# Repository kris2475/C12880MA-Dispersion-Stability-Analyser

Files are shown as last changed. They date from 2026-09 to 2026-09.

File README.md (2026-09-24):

# Multiwavelength Dispersion Analyser

A low-cost, highly portable optical sensing platform designed for field and lab use, pairing the **Hamamatsu C12880MA micro-spectrometer** with its **onboard PCB LED illumination source** to track stability, flocculation, agglomeration, and sedimentation dynamics in complex liquid dispersions.

Traditional stability analysers rely on single-wavelength light sources and a single photodiode, capturing only a blunt aggregate transmission number. This project evolves that proven industrial concept into a full-spectrum (340 - 850 nm) optical tool. By monitoring every wavelength simultaneously, the system can decouple overall scattering mass from time-dependent particle size shifts, micro-bubble relaxation phases, and differential sedimentation.

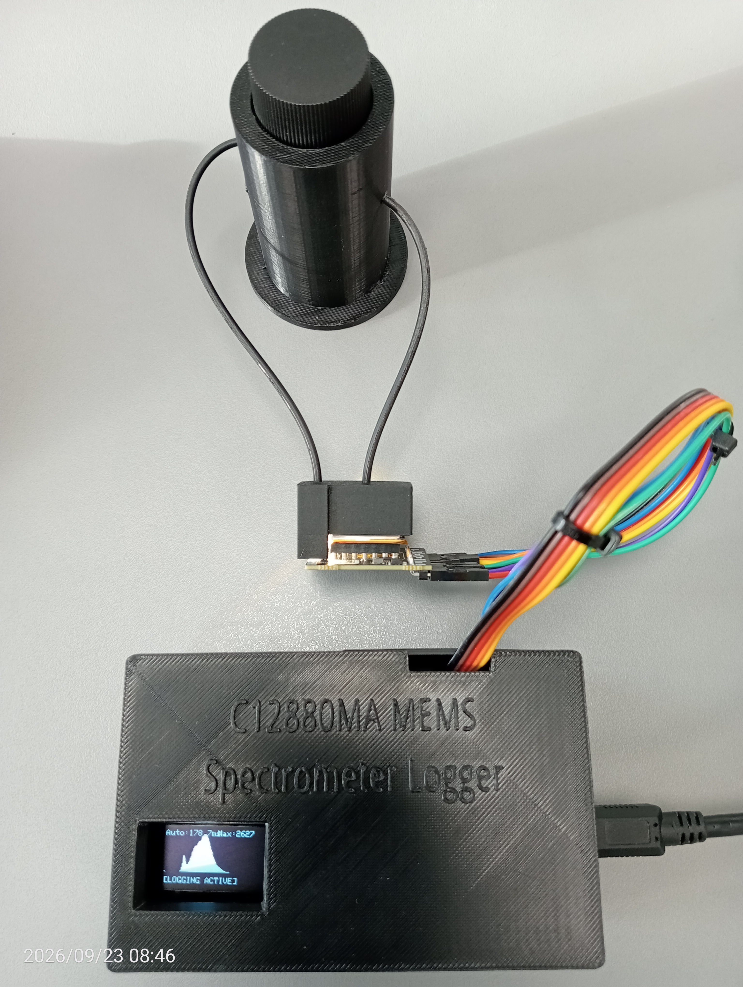
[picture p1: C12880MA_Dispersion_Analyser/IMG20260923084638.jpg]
Multiwavelength Dispersion Analyser


---

## System Architecture & Field Portability

Engineered for rapid deployment outside the traditional laboratory, the device combines low-power microcontrollers with precision optical hardware:

* **0° Transmission & Extinction Axis:** The primary operational path, tracking total optical density, scattering, and initial de-aeration/bubble-clearing behaviour immediately after sample agitation.
* **Multi-Angle Optical Probing:** Configurable housing geometry designed to capture multiwavelength extinction and scattering profiles across the entire visible-to-near-infrared spectrum.

---

## Sensor Layout & Dark Pixel Reference

The Hamamatsu C12880MA sensor array comprises 288 total channels. The 288-pixel spectral detector provides a full 340–850 nm spectral measurement at approximately 12 nm FWHM resolution. The first 87 columns (**P0 through P86**) correspond to a dedicated sequence of physically shielded pixels on the sensor die. 

Rather than relying on an isolated external reference, these masked elements capture the sensor's native dark current, reset noise, and electronic baseline offsets in real time. The firmware uses this continuous block for thermal drift and offset subtraction on every individual scan, ensuring high repeatability in field conditions.

---

## Hardware Bill of Materials

* **Micro-Spectrometer & Light Source:** Hamamatsu C12880MA micro-spectrometer module utilising its **onboard PCB LED** as the illumination source (288-pixel CMOS image sensor with a reflection grating, 340 - 850 nm range; features 87 optically shielded dark pixels, P0 - P86, for real-time baseline noise subtraction).
* **Microcontroller:** ESP32 Dev Module (handling precise clock timing, ADC attenuation, OLED interface, and SD card logging).
* **Housing:** Custom 3D-printed matte black, lightweight portable enclosure optimised for standard optical vials/cuvettes and secure alignment with the spectrometer PCB.

---

## Dispersion Physics & Kinetic Analysis Pipeline

By capturing full-spectrum temporal data (e.g., minute-by-minute logs of shaken suspensions like turmeric or starch in water), the companion Python and firmware tools extract rich kinetic metrics underpinned by fundamental optical scattering and fluid dynamics principles:

1. **Sedimentation Tracking (Total Scattering Mass & Stokes' Law):** 
   * Monitors the total integrated intensity across all active wavelengths to evaluate overall suspended particle mass in real time.
   * Captures initial preparation artefacts, such as micro-bubble clearance and de-aeration phases immediately following sample agitation.
   * Reflects bulk particle concentration changes governed by gravitational settling dynamics (approximate Stokes' settling), where particle size, mass density differentials, and fluid viscosity dictate how matter migrates relative to the optical path.

2. **Agglomeration & Flocculation Tracking (Mie vs. Rayleigh Scattering & Spectral Slope Ratios):** 
   * Computes multiwavelength intensity ratios (e.g., $650\text{nm} / 450\text{nm}$) to detect continuous changes in spectral tilt and slope as particles interact and evolve.
   * **Rayleigh Regime ($d \ll \lambda$):** Applies when scattering particles are significantly smaller than the incident wavelength (typically $d < \lambda / 10$). Here, scattering efficiency scales steeply with the inverse fourth power of wavelength ($\lambda^{-4}$), causing much stronger scattering at shorter wavelengths (blue/UV) than longer wavelengths (red/NIR).
   * **Mie Regime ($d \approx \lambda$):** Applies when particle diameters are comparable to the wavelength of light, which is characteristic of practical suspensions, emulsions, and colloidal dispersions (such as starch or turmeric granules). In this regime, the wavelength dependence becomes much weaker and non-monotonic, scaling inversely with $\lambda$ to a lower power or exhibiting complex resonance patterns.
   * **Tracking Agglomeration:** By measuring how the full spectrum shifts across these optical regimes, the system isolates differential sedimentation and flocculation, revealing how heavier or coarser aggregates drop out rapidly while finer fractions remain suspended or form loose structural clusters that alter the wavelength-dependent scattering profile.

3. **Peak Wavelength & Structural Shape Shifts:** 
   * Identifies discrete shifts, broadening, or fluctuations in maximum scattering peaks over extended time series.
   * Decouples bulk chemical identity and baseline intensity changes from physical structural modifications, confirming whether the primary scattering centre remains stable while localised clustering, swelling, or spatial redistribution occurs within the dispersion.

---

## Firmware & Field-Ready Data Logging

The companion ESP32 firmware features an interactive serial interface supporting deployment in the field:
* **Real-Time Auto-Exposure:** Automatically scales integration time (11 ms to 1 s) to keep peak ADC values within optimal target bounds.
* **Periodic Interval Datalogging (`LOG <sec>`):** Automatically saves timestamped spectral frames to an attached SD card at user-defined intervals (ideal for tracking long-term stability curves over 30 to 60+ minutes).
* **Burst Capture (`B`):** Rapidly captures a RAM buffer following a pre-flight auto-exposure stabilisation phase.
* **Metadata Tagging (`COMMENT <text>`):** Appends custom text tags directly to log entries for field sample tracking.

## Experimental Results

To validate the multiwavelength pipeline under real-world conditions, a dynamic stability test was performed using a turmeric-in-water dispersion over a 36-minute time series. Following manual agitation, the sample was logged continuously to capture both transient mixing artifacts and long-term suspension relaxation.

### 1. Raw Spectral Evolution: Waterfall & Spectrogram View
The initial optical behavior of the dispersion is captured across the raw spectral response. 

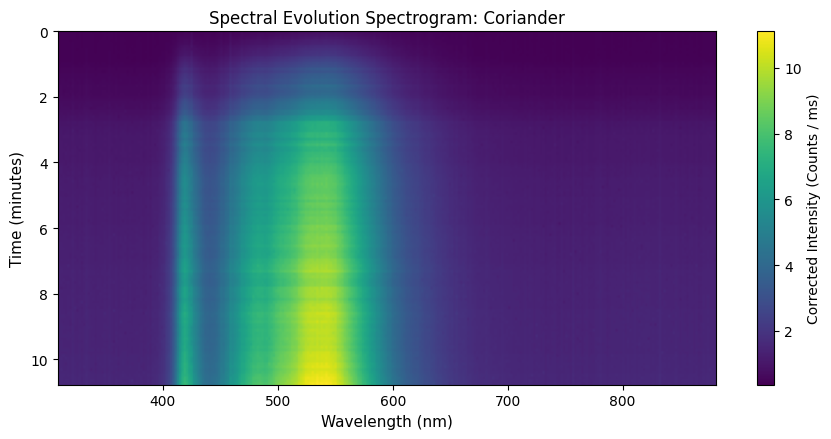
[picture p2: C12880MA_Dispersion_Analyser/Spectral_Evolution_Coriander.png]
Waterfall plot of coriander dispersion spectra
 
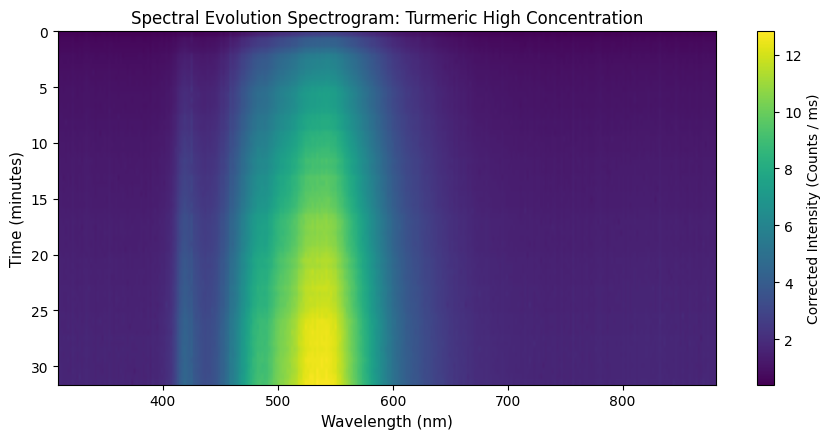
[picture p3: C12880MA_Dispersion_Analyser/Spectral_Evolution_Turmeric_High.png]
Waterfall plot of turmeric_high dispersion spectra
 
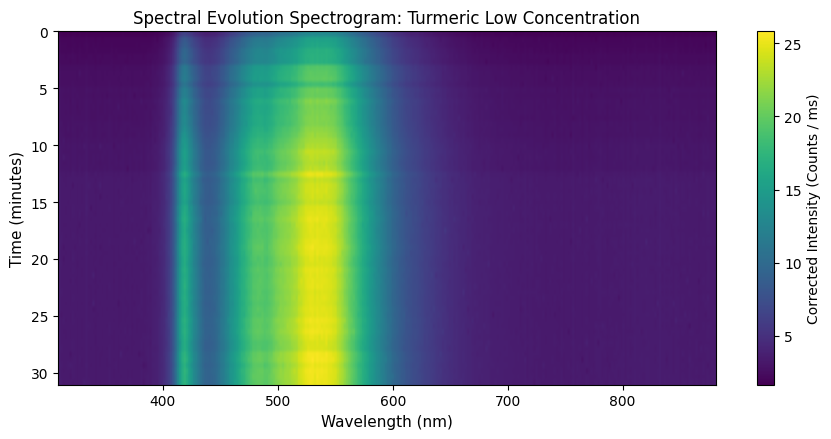
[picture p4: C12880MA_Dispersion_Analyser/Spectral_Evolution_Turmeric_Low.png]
Waterfall plot of tumeric_low dispersion spectra
 
---

* **What we are seeing:** The raw waterfall/overlay plot above demonstrates the complete spectral signature captured by the Hamamatsu C12880MA spectrometer, ranging from the UV-visible cutoff through the characteristic curcuminoid absorption and scattering bands (peaking around 560 – 590 nm). 
* **Connection to the Pipeline:** This corresponds directly to the raw data input stage of our pipeline. Unlike a single-wavelength sensor that only logs a single scalar value, this full spectral sweep captures the entire optical envelope at every 60-second time step. The dense vertical lines visible in early iterations highlight how the hardware pixel resolution responds across the spectrum before baseline dark-correction is applied.

---

### 2. Kinetic Breakdown & Multi-Parameter Analysis

To understand the physical phenomena occurring inside the vial across the multiple spice suspension trials (**Turmeric High**, **Turmeric Low**, and **Coriander**), the raw spectra were processed through the multiwavelength analytical framework. This yielded three distinct diagnostic time profiles revealing how each sample's optical properties change over time due to processes like micro-bubble dissipation, particle rearrangement, and structural settling.

* **Important Context:** Each dispersion was vigorously shaken before logging, which significantly influences initial spectral readings due to temporary air-bubble generation and artificially depressed optical transmission. Following the initial clearance phase, distinct sedimentation and particle dynamics unfold depending on the substance and concentration.

---

### Panel 1: Sedimentation Tracking (Total Scattering Mass)
* **What it shows:** Normalised total integrated intensity starts at a baseline of 100% and climbs progressively across all trials, though with drastically different magnitudes:
  * **Turmeric Low Concentration** rises to approximately 200%.
  * **Turmeric High Concentration** increases to over 400%.
  * **Coriander** climbs steeply up to nearly 800%.
* **Physics Connection:** This unmasks the initial micro-bubble clearance phase. Manual shaking introduces micro-bubbles that severely scatter and block light, depressing early signal counts. As these bubbles rapidly migrate to the surface and dissipate, the optical path clears, revealing the true underlying backscattering behavior and localised particle accumulation within the probe's sensing zone.

### Panel 2: Agglomeration / Flocculation Tracking (Spectral Slope)
* **What it shows:** The intensity ratio between 650 nm and 450 nm demonstrates a consistent downward trajectory across all datasets from different initial points:
  * **Coriander** drops from ~1.25 down to a stable baseline around ~0.78.
  * **Turmeric High** drops from ~2.75 down to ~1.5.
  * **Turmeric Low** drops from ~1.06 down to ~0.75.
* **Physics Connection:** The steep early drop is heavily driven by the transient clearance of micro-bubbles. Once the optical path clears, the true physical dynamics emerge—reflecting structural relaxation, particle rearrangement, and changes in multi-wavelength scattering efficiencies before flattening into stable operational baselines.

### Panel 3: Peak Shift Tracking
* **What it shows:** The apex wavelength of the primary dispersion band oscillates within a stable spectral band (e.g., fluctuating between ~590 nm and ~602 nm for Coriander), featuring sharp quantisation steps and occasional transient spikes.
* **Physics Connection:** This demonstrates the operational limits of pixel-resolution quantisation on discrete spectrometer arrays. As the true optical peak center shifts subtly, the algorithm snaps between adjacent physical pixel columns, while transient spikes capture momentary bulk shifts where local particle migrations alter the spectral envelope's centre of mass.

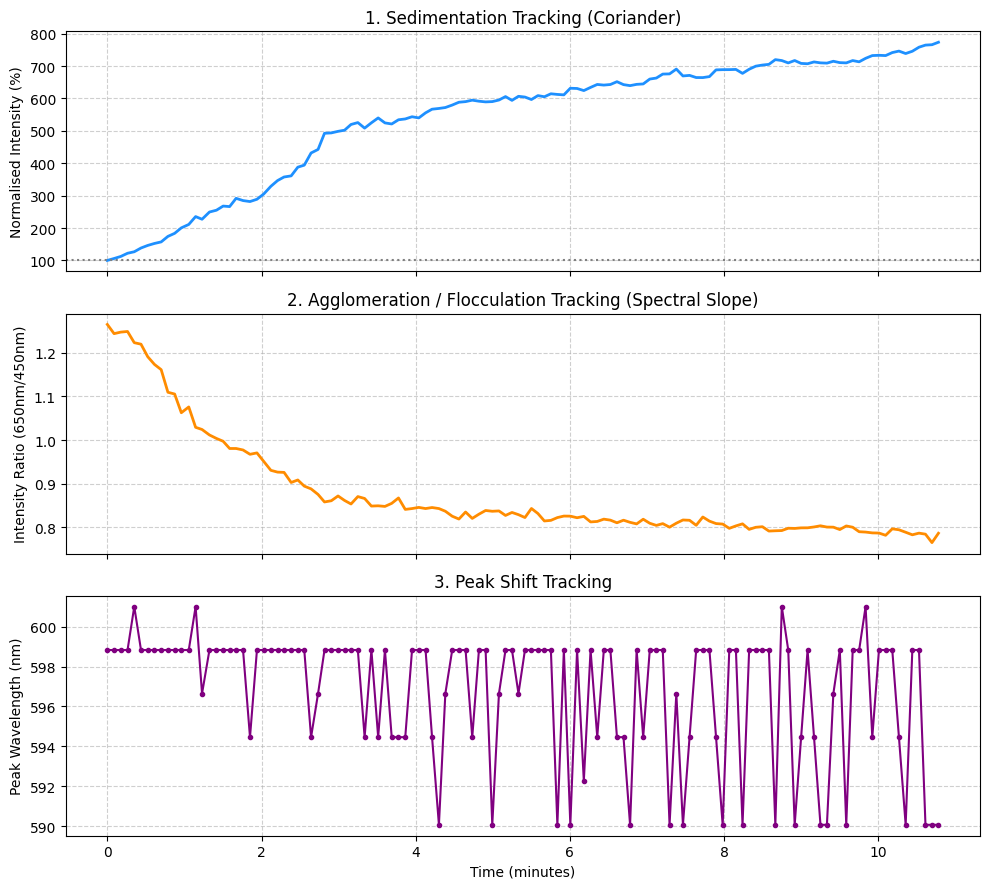
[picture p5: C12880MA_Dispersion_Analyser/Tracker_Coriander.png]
Three-panel kinetic analysis of coriander dispersion

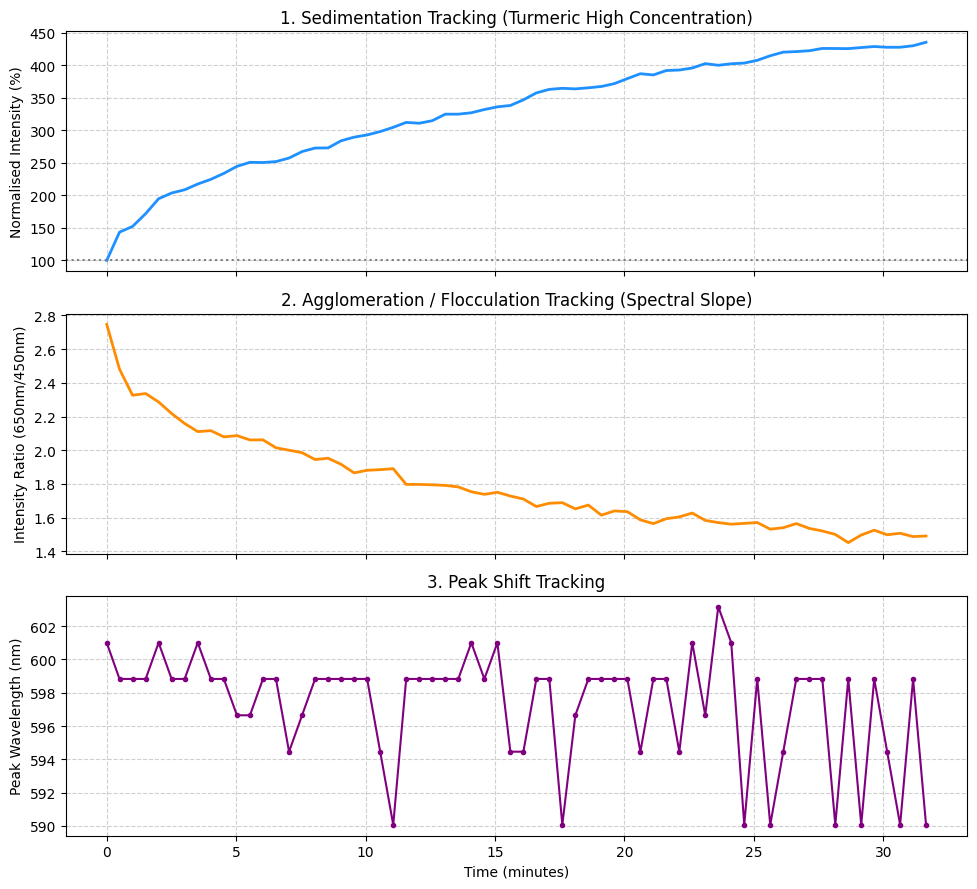
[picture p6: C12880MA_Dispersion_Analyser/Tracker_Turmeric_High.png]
Three-panel kinetic analysis of turmeric_high dispersion

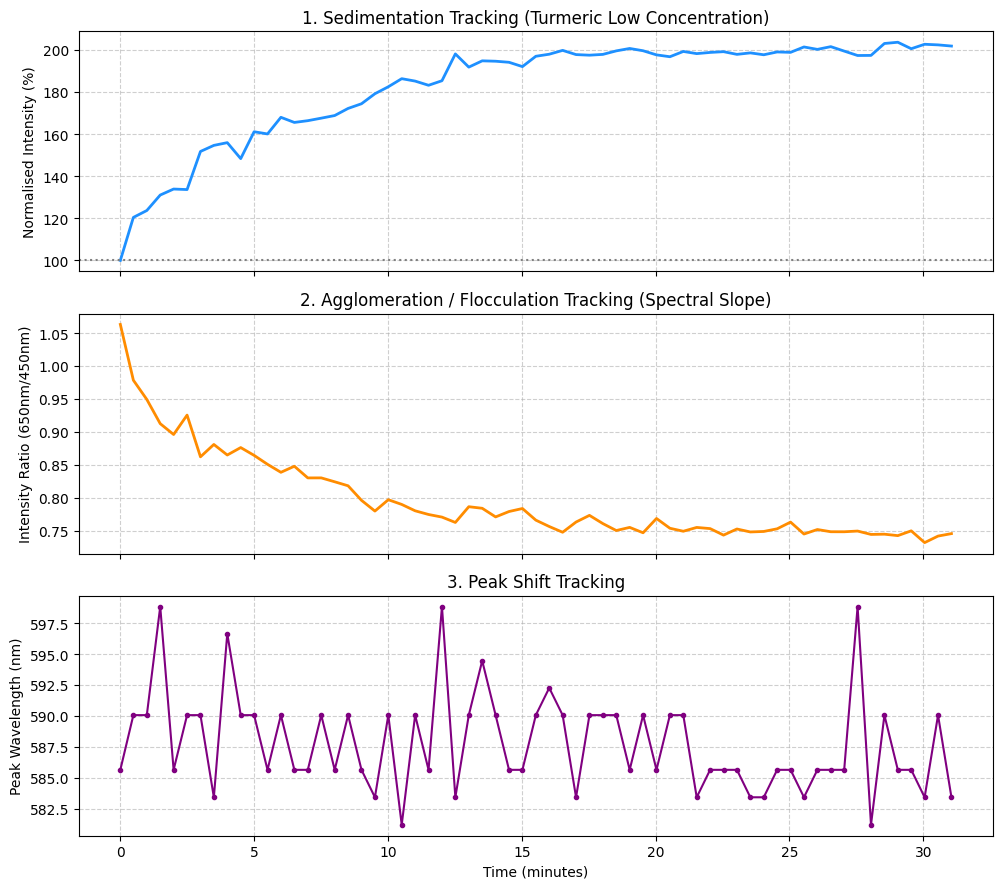
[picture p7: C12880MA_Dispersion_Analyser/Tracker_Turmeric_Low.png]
Three-panel kinetic analysis of turmeric_low dispersion


### 3. Sedimentation vs. Spectral Ratio

### Correlation and Regression Dynamics

The strong negative Pearson correlation coefficients observed across all spice dispersion trials—**Turmeric Low Concentration** ($r = -0.9834$), **Turmeric High Concentration** ($r = -0.9880$), and **Coriander** ($r = -0.9419$)—are clearly illustrated in the comparative scatter plot below. 

These visualisations confirm a robust inverse relationship mapping optical scattering mass (sedimentation proxy) against spectral slope dynamics, which are heavily influenced during the early phase by micro-bubble clearance and subsequent particle rearrangement.

* **Turmeric High Concentration:** $y = -0.003x + 2.867$ ($R^2 = 0.98$)
* **Turmeric Low Concentration:** $y = -0.003x + 1.283$ ($R^2 = 0.97$)
* **Coriander:** $y = -0.001x + 1.196$ ($R^2 = 0.89$)

### Optical Confounding: Physical Scattering vs. Chemical Absorption

While the $650\,\text{nm} / 450\,\text{nm}$ ratio provides a clean empirical proxy for tracking sedimentation dynamics, it is inherently subject to optical confounding. In suspensions containing complex organic matter like turmeric, physical particle scattering and chemical absorption occur simultaneously and blend together into a single measurement:

* **The Chemical Component:** Turmeric contains curcumin, a potent pigment that heavily absorbs blue light around $430\text{--}450\,\text{nm}$. This strong chemical absorption artificially elevates the starting ratio compared to neutral spices or mineral silts.
* **The Physical Component:** As larger aggregates and particles settle out, the overall cloudiness drops, altering the Mie-scattering slope across the spectrum. 

Rather than acting as a pure, isolated measure of physical turbidity, the $650\,\text{nm} / 450\,\text{nm}$ ratio captures a coupled fingerprint of both particle-size evolution and chemical concentration. While this complicates single-variable physical modeling, it creates a highly repeatable, distinct composite signature that downstream machine learning pipelines can leverage to simultaneously resolve physical settling behavior and chemical composition.

### 3. Sedimentation vs. Spectral Ratio

### Correlation and Regression Dynamics

The strong negative Pearson correlation coefficients observed across all spice dispersion trials—**Turmeric Low Concentration** ($r = -0.9834$), **Turmeric High Concentration** ($r = -0.9880$), and **Coriander** ($r = -0.9419$)—are clearly illustrated in the comparative scatter plot below. 

These visualisations confirm a robust inverse relationship mapping optical scattering mass (sedimentation proxy) against spectral slope dynamics, which are heavily influenced during the early phase by micro-bubble clearance and subsequent particle rearrangement.

* **Turmeric High Concentration:** $y = -0.003x + 2.867$ ($R^2 = 0.98$)
* **Turmeric Low Concentration:** $y = -0.003x + 1.283$ ($R^2 = 0.97$)
* **Coriander:** $y = -0.001x + 1.196$ ($R^2 = 0.89$)

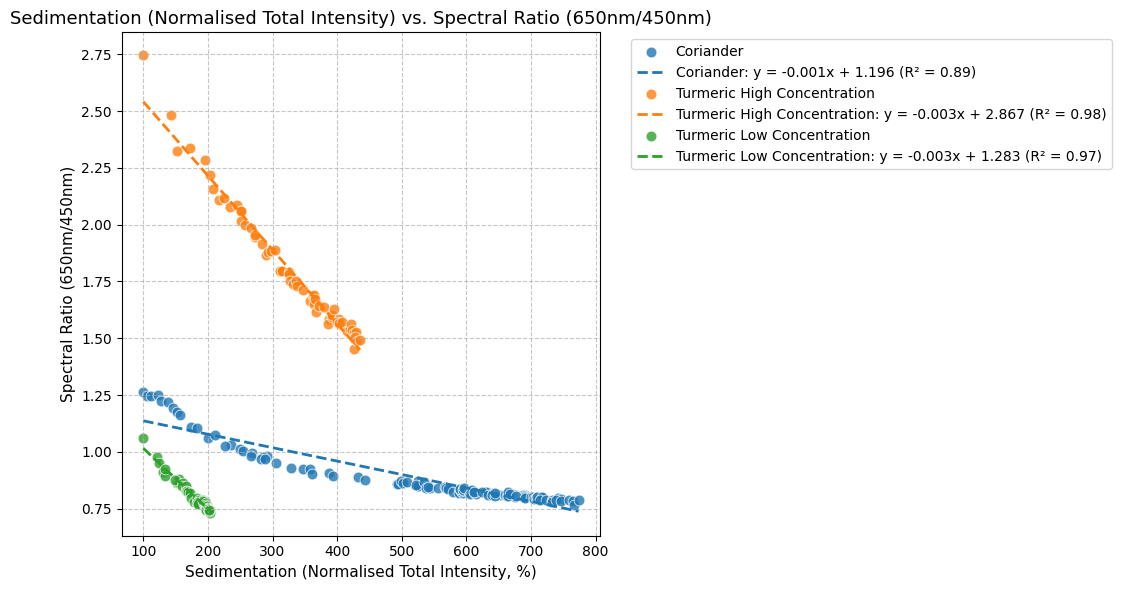
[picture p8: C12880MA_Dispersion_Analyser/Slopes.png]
Sedimentation vs. Spectral Ratio


#### Correlation Analysis & Physical Coupling
* **Axes & Range:** The plot maps the Normalised Total Intensity (%) from a baseline of 100 % up to approximately 780 % on the x-axis - varying by substance up to ~205 % for Turmeric Low, ~440 % for Turmeric High, and ~780 % for Coriander - against the 650 nm/450 nm Spectral Ratio spanning from ~0.74 up to ~2.75 on the y-axis.
* **Inverse Proportionality:** As the Normalised Total Intensity increases across all trials (driven heavily in the initial phase by the rapid clearance of scattering micro-bubbles and enhanced optical path clarity), the Spectral Ratio systematically decreases for each respective dataset, following strong linear regression fits:
  * **Coriander:** $y = -0.001x + 1.196$ ($R^2 = 0.89$)
  * **Turmeric High Concentration:** $y = -0.003x + 2.867$ ($R^2 = 0.98$)
  * **Turmeric Low Concentration:** $y = -0.003x + 1.283$ ($R^2 = 0.97$)
* **Physical Significance:** This tight coupling demonstrates that the optical evolution of the dispersions is governed by simultaneous mechanisms: the progressive elimination of transient micro-bubble and scattering obstructions aligns directly with the structural relaxation and settling of larger particle agglomerates into a stable colloidal state.

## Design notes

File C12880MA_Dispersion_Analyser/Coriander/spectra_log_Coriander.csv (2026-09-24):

Timestamp | IntegrationTime_us | LED_State | Comment | Max_ADC | P0 | P1 | P2 | P3 | P4 | P5 | P6 | P7 | P8 | P9 | P10 | P11 | P12 | P13 | P14 | P15 | P16 | P17 | P18 | P19 | P20 | P21 | P22 | P23 | P24 | P25 | P26 | P27 | P28 | P29 | P30 | P31 | P32 | P33 | P34 | P35 | P36 | P37 | P38 | P39 | P40 | P41 | P42 | P43 | P44 | P45 | P46 | P47 | P48 | P49 | P50 | P51 | P52 | P53 | P54
2026-09-23 20:37:54.456 | 1000000 | ON | coriander | 861 | 371 | 428 | 417 | 416 | 421 | 414 | 448 | 416 | 406 | 420 | 403 | 429 | 436 | 425 | 419 | 407 | 400 | 410 | 400 | 413 | 416 | 405 | 432 | 409 | 400 | 409 | 369 | 411 | 405 | 404 | 394 | 402 | 393 | 393 | 403 | 405 | 402 | 397 | 389 | 414 | 391 | 419 | 406 | 400 | 416 | 425 | 405 | 432 | 411 | 418 | 448 | 442 | 476 | 490 | 483
2026-09-23 20:37:59.706 | 1000000 | ON | coriander | 997 | 368 | 446 | 422 | 412 | 420 | 413 | 444 | 410 | 402 | 418 | 400 | 418 | 439 | 431 | 416 | 410 | 398 | 406 | 406 | 401 | 415 | 411 | 435 | 412 | 400 | 411 | 395 | 403 | 401 | 406 | 400 | 401 | 391 | 418 | 410 | 402 | 400 | 387 | 398 | 414 | 391 | 419 | 404 | 399 | 413 | 429 | 411 | 435 | 416 | 430 | 458 | 454 | 496 | 528 | 533
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

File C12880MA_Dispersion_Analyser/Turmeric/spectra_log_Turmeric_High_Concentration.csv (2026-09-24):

Timestamp | IntegrationTime_us | LED_State | Comment | Max_ADC | P0 | P1 | P2 | P3 | P4 | P5 | P6 | P7 | P8 | P9 | P10 | P11 | P12 | P13 | P14 | P15 | P16 | P17 | P18 | P19 | P20 | P21 | P22 | P23 | P24 | P25 | P26 | P27 | P28 | P29 | P30 | P31 | P32 | P33 | P34 | P35 | P36 | P37 | P38 | P39 | P40 | P41 | P42 | P43 | P44 | P45 | P46 | P47 | P48 | P49 | P50 | P51 | P52 | P53 | P54
2026-09-24 07:35:05.778 | 932296 | ON | Turmeric_Strong | 2675 | 368 | 464 | 464 | 463 | 463 | 461 | 502 | 459 | 455 | 462 | 448 | 478 | 506 | 483 | 464 | 453 | 441 | 449 | 452 | 461 | 468 | 457 | 495 | 451 | 441 | 460 | 434 | 455 | 451 | 458 | 436 | 443 | 441 | 437 | 451 | 451 | 448 | 432 | 437 | 458 | 432 | 475 | 461 | 442 | 466 | 481 | 455 | 491 | 463 | 466 | 506 | 497 | 553 | 566 | 559
2026-09-24 07:35:35.381 | 612846 | ON | Turmeric_Strong | 2591 | 368 | 402 | 402 | 397 | 400 | 398 | 426 | 389 | 386 | 401 | 400 | 409 | 432 | 412 | 399 | 400 | 389 | 391 | 399 | 401 | 405 | 394 | 419 | 399 | 384 | 407 | 388 | 402 | 401 | 394 | 393 | 397 | 389 | 384 | 400 | 393 | 396 | 382 | 389 | 400 | 381 | 409 | 402 | 399 | 409 | 425 | 413 | 432 | 419 | 438 | 480 | 471 | 530 | 560 | 574
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

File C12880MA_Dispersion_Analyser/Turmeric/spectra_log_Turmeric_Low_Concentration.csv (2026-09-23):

Timestamp | IntegrationTime_us | LED_State | Comment | Max_ADC | P0 | P1 | P2 | P3 | P4 | P5 | P6 | P7 | P8 | P9 | P10 | P11 | P12 | P13 | P14 | P15 | P16 | P17 | P18 | P19 | P20 | P21 | P22 | P23 | P24 | P25 | P26 | P27 | P28 | P29 | P30 | P31 | P32 | P33 | P34 | P35 | P36 | P37 | P38 | P39 | P40 | P41 | P42 | P43 | P44 | P45 | P46 | P47 | P48 | P49 | P50 | P51 | P52 | P53 | P54
2026-09-23 09:37:56.816 | 195152 | ON | Turmeric | 2559 | 377 | 344 | 339 | 336 | 346 | 336 | 349 | 342 | 336 | 343 | 336 | 341 | 352 | 339 | 336 | 336 | 331 | 341 | 336 | 336 | 339 | 336 | 341 | 336 | 329 | 338 | 335 | 333 | 351 | 336 | 323 | 336 | 329 | 336 | 334 | 332 | 350 | 335 | 338 | 350 | 346 | 355 | 361 | 371 | 384 | 400 | 418 | 464 | 481 | 564 | 649 | 766 | 932 | 1109 | 1206
2026-09-23 09:38:26.016 | 161374 | ON | Turmeric | 2536 | 379 | 338 | 336 | 334 | 339 | 329 | 354 | 336 | 330 | 339 | 333 | 336 | 347 | 336 | 333 | 335 | 326 | 336 | 330 | 325 | 334 | 336 | 337 | 336 | 330 | 336 | 336 | 336 | 340 | 331 | 331 | 336 | 329 | 335 | 330 | 329 | 338 | 330 | 336 | 338 | 337 | 358 | 361 | 342 | 384 | 400 | 437 | 471 | 510 | 586 | 677 | 812 | 1005 | 1169 | 1292
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

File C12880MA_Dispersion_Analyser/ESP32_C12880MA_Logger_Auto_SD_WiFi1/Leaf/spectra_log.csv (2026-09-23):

Timestamp | IntegrationTime_us | LED_State | Comment | Max_ADC | P0 | P1 | P2 | P3 | P4 | P5 | P6 | P7 | P8 | P9 | P10 | P11 | P12 | P13 | P14 | P15 | P16 | P17 | P18 | P19 | P20 | P21 | P22 | P23 | P24 | P25 | P26 | P27 | P28 | P29 | P30 | P31 | P32 | P33 | P34 | P35 | P36 | P37 | P38 | P39 | P40 | P41 | P42 | P43 | P44 | P45 | P46 | P47 | P48 | P49 | P50 | P51 | P52 | P53 | P54
20/09/2026 10:50 | 11000 | OFF | DAYLIGHT | 3851 | 318 | 320 | 321 | 327 | 338 | 339 | 348 | 355 | 357 | 371 | 370 | 381 | 401 | 400 | 410 | 429 | 433 | 451 | 445 | 441 | 462 | 450 | 469 | 476 | 489 | 526 | 544 | 577 | 637 | 692 | 786 | 871 | 988 | 1195 | 1388 | 1606 | 1745 | 1817 | 1862 | 1904 | 1931 | 1959 | 1967 | 1991 | 2012 | 2018 | 2083 | 2222 | 2306 | 2543 | 2665 | 2864 | 3089 | 3326 | 3471
20/09/2026 10:50 | 11000 | OFF | DAYLIGHT | 3839 | 320 | 322 | 326 | 322 | 337 | 329 | 343 | 358 | 355 | 371 | 369 | 384 | 400 | 398 | 411 | 432 | 423 | 445 | 445 | 433 | 448 | 448 | 464 | 481 | 485 | 528 | 543 | 576 | 627 | 688 | 773 | 877 | 994 | 1200 | 1385 | 1597 | 1734 | 1809 | 1854 | 1887 | 1929 | 1966 | 1969 | 1999 | 2001 | 2020 | 2083 | 2218 | 2330 | 2511 | 2678 | 2879 | 3107 | 3314 | 3443
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

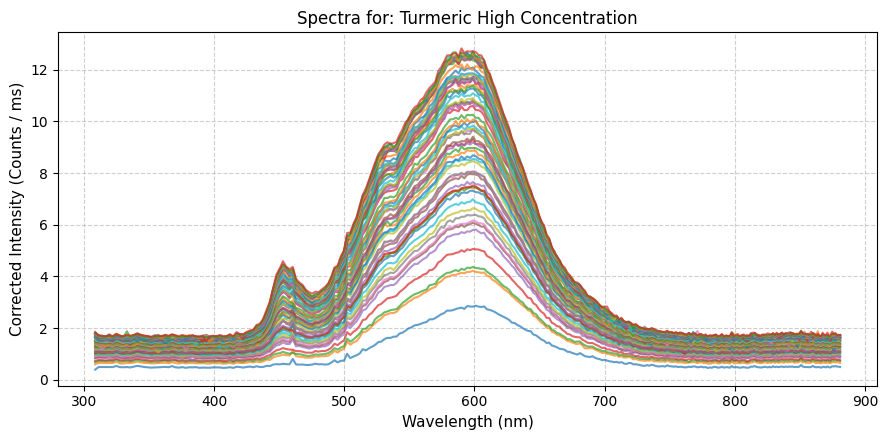
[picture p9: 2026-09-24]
C12880MA_Dispersion_Analyser/Spectra_Turmeric_High.png

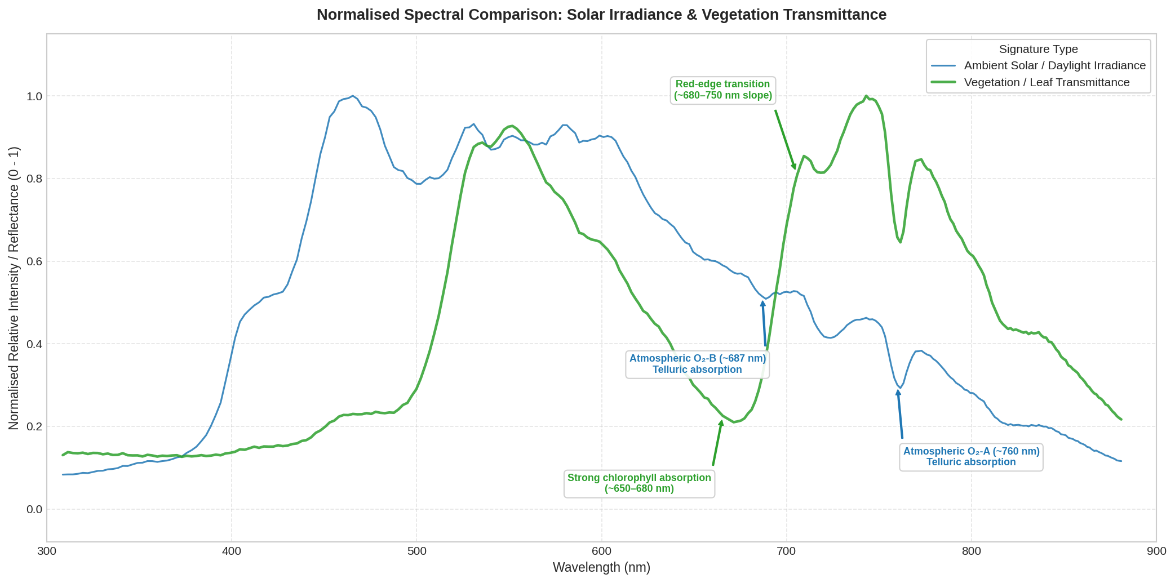
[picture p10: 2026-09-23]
C12880MA_Dispersion_Analyser/ESP32_C12880MA_Logger_Auto_SD_WiFi1/Leaf/Spectrum.png

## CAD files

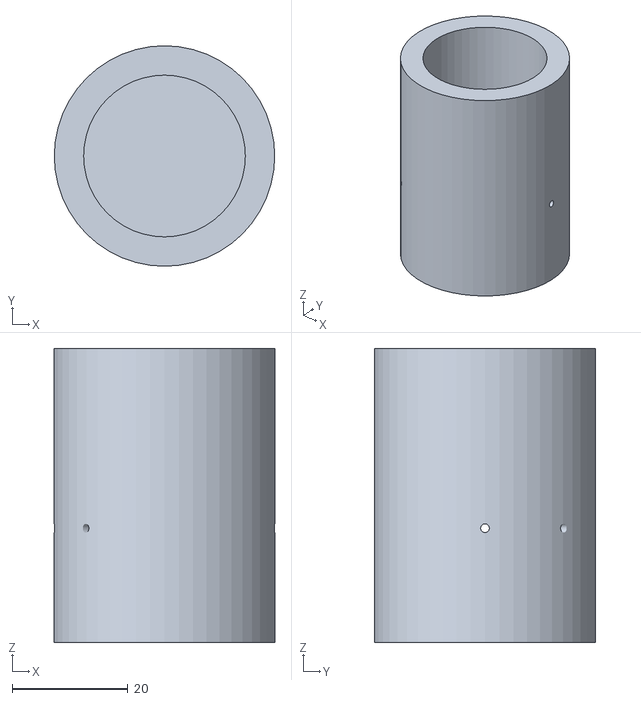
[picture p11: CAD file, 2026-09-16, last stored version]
C12880MA_Dispersion_Analyser/Dispersion.stl
38.1 x 38.1 x 50.8

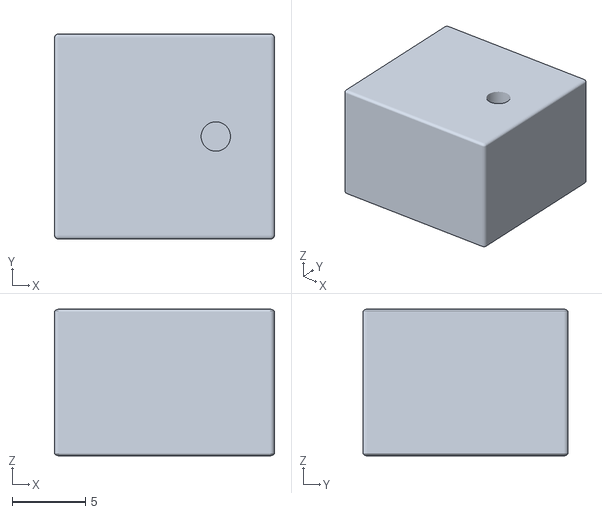
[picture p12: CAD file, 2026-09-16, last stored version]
C12880MA_Dispersion_Analyser/Dispersion_LED.stl
15.0 x 14.0 x 10.0

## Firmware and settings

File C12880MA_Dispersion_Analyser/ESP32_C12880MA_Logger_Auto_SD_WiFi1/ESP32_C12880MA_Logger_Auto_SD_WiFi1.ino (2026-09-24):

#include <Arduino.h>
#include <Wire.h>
#include <Adafruit_GFX.h>
#include <Adafruit_SSD1306.h>
#include <SPI.h>
#include <SD.h>
#include <WiFi.h>
#include <time.h>
#include <sys/time.h>

// ============================================================
// WIFI & NTP CONFIGURATION
// ============================================================
#define PRIMARY_SSID     ""
#define PRIMARY_PASS     ""

#define FALLBACK_SSID    ""
#define FALLBACK_PASS    ""

const char* ntpServer = "pool.ntp.org";
const long  gmtOffset_sec = 0;       // Adjust for your timezone offset in seconds (e.g., 3600 for UTC+1)
const int   daylightOffset_sec = 0;   // Adjust for daylight savings if applicable

// ============================================================
// OLED CONFIGURATION
// ============================================================
#define SCREEN_WIDTH  128
#define SCREEN_HEIGHT 64
#define OLED_RESET    -1
Adafruit_SSD1306 display(SCREEN_WIDTH, SCREEN_HEIGHT, &Wire, OLED_RESET);

// ============================================================
// PINS CONFIGURATION
// ============================================================
#define C12880MA_CLK_PIN      16
#define C12880MA_ST_PIN       17
#define C12880MA_VIDEO_PIN    34
#define LED_ILLUM_PIN         32
#define SD_CS_PIN             5   // Standard SPI CS for SD Card
#define SPECTROGRAPH_CHANNELS 288

// ============================================================
// SPECTROMETER DATA & STATE
// ============================================================
uint16_t spectrographData[SPECTROGRAPH_CHANNELS];
uint16_t currentMaxIntensity = 0;
uint16_t currentMinIntensity = 4095;

// System Controls
bool ledState = false;              // LED OFF by default
String userComment = "DEFAULT";     // Optional comment string for CSV logs
bool requestSaveToSD = false;       // Flag triggered via 'S' command

// Auto-Integration State
bool autoIntegrationEnabled = false;
const uint16_t TARGET_MAX_INTENSITY = 2500; 

// Timed Logging State (LOG <seconds>)
unsigned long logIntervalMs = 0;
unsigned long lastLogTime = 0;
bool timedLoggingActive = false;

// Burst Buffer State (10 frames x 288 channels)
#define BURST_SIZE 10
uint16_t burstBuffer[BURST_SIZE][SPECTROGRAPH_CHANNELS];
unsigned long burstIntegrationTimes[BURST_SIZE];
uint16_t burstMaxIntensities[BURST_SIZE];
bool isBursting = false;
int burstCount = 0;

// ============================================================
// C12880MA TIMING
// ============================================================
const unsigned long CLK_PERIOD_US = 2;
const unsigned long CLK_HALF_US   = 1;

unsigned long currentIntegrationTimeUs = 20000; // Default 20 ms
const unsigned long minIntegrationTimeUs = 11000;
const unsigned long maxIntegrationTimeUs = 1000000;

// ============================================================
// FUNCTION PROTOTYPES
// ============================================================
void connectWiFi();
void readSpectrometer();
void clockPulse();
void handleSerialCommands();
void printHelpMenu();
void updateDisplay();
void saveSpectrumToSD();
void writeBurstToSD();
void updateAutoIntegration();
String getFormattedTimestamp();

// ============================================================
// SETUP
// ============================================================
void setup() {
  Serial.begin(115200);
  delay(500);

  Serial.println(F("========================================"));
  Serial.println(F(" C12880MA ESP32 + WIFI + NTP + LOGGING"));
  Serial.println(F("========================================"));

  // LED OFF initially
  pinMode(LED_ILLUM_PIN, OUTPUT);
  digitalWrite(LED_ILLUM_PIN, LOW);

  // Initialize OLED
  Wire.begin(21, 22);
  if (!display.begin(SSD1306_SWITCHCAPVCC, 0x3C)) {
    Serial.println(F("[ERROR] OLED allocation failed!"));
  }
  display.clearDisplay();
  display.setTextColor(SSD1306_WHITE);
  display.setTextSize(1);

  // Initialize Spectrometer GPIO
  pinMode(C12880MA_CLK_PIN, OUTPUT);
  pinMode(C12880MA_ST_PIN, OUTPUT);
  digitalWrite(C12880MA_CLK_PIN, LOW);
  digitalWrite(C12880MA_ST_PIN, LOW);

  // Initialize ADC
  analogSetPinAttenuation(C12880MA_VIDEO_PIN, ADC_11db);
  analogReadResolution(12);

  // Initialize SD Card
  if (!SD.begin(SD_CS_PIN)) {
    Serial.println(F("[WARNING] SD Card Mount Failed. Logging disabled."));
  } else {
    Serial.println(F("[INFO] SD Card Initialized Successfully."));
  }

  // Connect to WiFi and sync time
  connectWiFi();

  printHelpMenu();

  // Sacrificial scan
  Serial.println(F("[INIT] Performing first sacrificial scan..."));
  readSpectrometer();
  Serial.println(F("[INIT] Measurement ready"));
  Serial.println();
}

// ============================================================
// MAIN LOOP
// ============================================================
void loop() {
  // 1. Process Serial Commands
  handleSerialCommands();

  // 2. Handle Burst Capture Mode if Active
  if (isBursting) {
    readSpectrometer();

    for (int i = 0; i < SPECTROGRAPH_CHANNELS; i++) {
      burstBuffer[burstCount][i] = spectrographData[i];
    }
    burstIntegrationTimes[burstCount] = currentIntegrationTimeUs;
    burstMaxIntensities[burstCount] = currentMaxIntensity;
    burstCount++;

    display.clearDisplay();
    display.setCursor(0, 0);
    display.print(F("BURST CAPTURE"));
    display.setCursor(0, 20);
    display.print(F("Scan #: "));
    display.print(burstCount);
    display.print(F("/10"));
    display.display();

    if (burstCount >= BURST_SIZE) {
      display.clearDisplay();
      display.setCursor(0, 0);
      display.print(F("WRITING BURST..."));
      display.display();

      writeBurstToSD();
      isBursting = false;
      Serial.println(F("[SD] 10-frame Burst complete and appended to /spectra_log.csv"));
    }
    return;
  }

  // 3. Normal Acquisition Loop
  readSpectrometer();

  // Update Auto-Integration if enabled
  if (autoIntegrationEnabled) {
    updateAutoIntegration();
  }

  // Handle single frame save request
  if (requestSaveToSD) {
    saveSpectrumToSD();
    requestSaveToSD = false;
  }

  // Handle Timed Periodic Logging (LOG <seconds>)
  if (timedLoggingActive && (millis() - lastLogTime >= logIntervalMs)) {
    lastLogTime = millis();
    saveSpectrumToSD();
    Serial.println(F("[LOG] Periodic spectrum frame logged to SD."));
  }

  // 4. Update OLED
  updateDisplay();
}

// ============================================================
// WIFI CONNECTION & NTP SYNC
// ============================================================
void connectWiFi() {
  Serial.print(F("[WIFI] Connecting to primary: "));
  Serial.println(PRIMARY_SSID);
  
  WiFi.begin(PRIMARY_SSID, PRIMARY_PASS);

  unsigned long startAttemptTime = millis();
  while (WiFi.status() != WL_CONNECTED && millis() - startAttemptTime < 10000) {
    delay(500);
    Serial.print(".");
  }

  // Try fallback if primary failed
  if (WiFi.status() != WL_CONNECTED) {
    Serial.println(F("\n[WIFI] Primary failed. Trying fallback: "));
    Serial.println(FALLBACK_SSID);
    WiFi.begin(FALLBACK_SSID, FALLBACK_PASS);
    
    startAttemptTime = millis();
    while (WiFi.status() != WL_CONNECTED && millis() - startAttemptTime < 10000) {
      delay(500);
      Serial.print(".");
    }
  }

  if (WiFi.status() == WL_CONNECTED) {
    Serial.println(F("\n[WIFI] Connected successfully!"));
    Serial.print(F("[WIFI] IP Address: "));
    Serial.println(WiFi.localIP());

    // Initialize and get NTP time
    configTime(gmtOffset_sec, daylightOffset_sec, ntpServer);
    Serial.println(F("[NTP] Synchronizing time..."));
    
    // Wait explicitly for real-world time to be populated (up to 5 seconds)
    struct tm timeinfo;
    unsigned long ntpStart = millis();
    bool timeSet = false;
    while (millis() - ntpStart < 5000) {
      if (getLocalTime(&timeinfo)) {
        timeSet = true;
        break;
      }
      delay(200);
    }

    if (timeSet) {
      Serial.println(F("[NTP] Time synchronized successfully with seconds tracking."));
    } else {
      Serial.println(F("[NTP] Failed to obtain time within timeout window."));
    }
  } else {
    Serial.println(F("\n[WIFI] Failed to connect to any network. Timestamps will default to uptime."));
  }
}

String getFormattedTimestamp() {
  struct tm timeinfo;
  struct timeval tv;
  
  // Get both standard time elements and microsecond offsets for high accuracy
  gettimeofday(&tv, NULL);
  if (!getLocalTime(&timeinfo)) {
    return String(millis()); // Fallback to millis if NTP unavailable
  }
  
  char timeBuffer[64];
  // Formats as YYYY-MM-DD HH:MM:SS.mmm (including milliseconds)
  int millisVal = (tv.tv_usec / 1000);
  snprintf(timeBuffer, sizeof(timeBuffer), "%04d-%02d-%02d %02d:%02d:%02d.%03d",
           timeinfo.tm_year + 1900, timeinfo.tm_mon + 1, timeinfo.tm_mday,
           timeinfo.tm_hour, timeinfo.tm_min, timeinfo.tm_sec, millisVal);
           
  return String(timeBuffer);
}

// ============================================================
// AUTO-INTEGRATION CONTROLLER
// ============================================================
void updateAutoIntegration() {
  if (currentMaxIntensity < 50) {
    currentIntegrationTimeUs = min(maxIntegrationTimeUs, currentIntegrationTimeUs * 2);
    return;
  }

  long error = (long)TARGET_MAX_INTENSITY - (long)currentMaxIntensity;
  if (abs(error) > 150) {
    float adjustmentRatio = (float)TARGET_MAX_INTENSITY / (float)currentMaxIntensity;
    long newTime = currentIntegrationTimeUs + (long)((float)currentIntegrationTimeUs * (adjustmentRatio - 1.0) * 0.5);
    currentIntegrationTimeUs = constrain(newTime, minIntegrationTimeUs, maxIntegrationTimeUs);
  }
}

// ============================================================
// CLOCK PULSE & READOUT
// ============================================================
void clockPulse() {
  digitalWrite(C12880MA_CLK_PIN, HIGH);
  delayMicroseconds(CLK_HALF_US);
  digitalWrite(C12880MA_CLK_PIN, LOW);
  delayMicroseconds(CLK_HALF_US);
}

void readSpectrometer() {
  digitalWrite(LED_ILLUM_PIN, ledState ? HIGH : LOW);
  if (ledState) {
    delay(2);
  }

  const unsigned long integrationClockComponent = 48UL * CLK_PERIOD_US;
  unsigned long stHighUs = 0;

  if (currentIntegrationTimeUs > integrationClockComponent) {
    stHighUs = currentIntegrationTimeUs - integrationClockComponent;
  } else {
    stHighUs = 1;
  }

  digitalWrite(C12880MA_CLK_PIN, LOW);
  digitalWrite(C12880MA_ST_PIN, LOW);
  delayMicroseconds(5);

  digitalWrite(C12880MA_ST_PIN, HIGH);
  delayMicroseconds(stHighUs);
  digitalWrite(C12880MA_ST_PIN, LOW);

  clockPulse();

  for (int i = 0; i < 86; i++) {
    clockPulse();
  }

  currentMaxIntensity = 0;
  currentMinIntensity = 4095;

  for (int i = 0; i < SPECTROGRAPH_CHANNELS; i++) {
    spectrographData[i] = analogRead(C12880MA_VIDEO_PIN);

    if (spectrographData[i] > currentMaxIntensity) {
      currentMaxIntensity = spectrographData[i];
    }
    if (spectrographData[i] < currentMinIntensity) {
      currentMinIntensity = spectrographData[i];
    }

    clockPulse();
  }

  digitalWrite(C12880MA_ST_PIN, HIGH);
  for (int i = 0; i < 7; i++) {
    clockPulse();
  }

  digitalWrite(C12880MA_CLK_PIN, LOW);
  digitalWrite(C12880MA_ST_PIN, LOW);
  digitalWrite(LED_ILLUM_PIN, LOW);
}

// ============================================================
// OLED UPDATE
// ============================================================
void updateDisplay() {
  display.clearDisplay();

  display.setCursor(0, 0);
  if (autoIntegrationEnabled) {
    display.print(F("Auto:"));
  } else {
    display.print(F("Int:"));
  }
  
  if (currentIntegrationTimeUs >= 1000000UL) {
    display.print(currentIntegrationTimeUs / 1000000.0, 1);
    display.print(F("s"));
  } else {
    display.print(currentIntegrationTimeUs / 1000.0, 1);
    display.print(F("ms"));
  }

  display.setCursor(68, 0);
  display.print(F("Max:"));
  display.print(currentMaxIntensity);

  // Show logging indicator if active
  if (timedLoggingActive) {
    display.setCursor(0, 56);
    display.print(F("[LOGGING ACTIVE]"));
  }

  for (int x = 0; x < 128; x++) {
    int specIndex = map(x, 0, 127, 0, SPECTROGRAPH_CHANNELS - 1);
    int barHeight = 0;

    if (currentMaxIntensity > currentMinIntensity) {
      barHeight = map(spectrographData[specIndex], currentMinIntensity, currentMaxIntensity, 0, 45);
    }
    barHeight = constrain(barHeight, 0, 45);

    display.drawFastVLine(x, 50 - barHeight, barHeight, SSD1306_WHITE);
  }
  display.display();
}

// ============================================================
// SD CARD LOGGING FUNCTIONS
// ============================================================
void saveSpectrumToSD() {
  bool fileExists = SD.exists("/spectra_log.csv");

  File dataFile = SD.open("/spectra_log.csv", FILE_APPEND);
  if (dataFile) {
    if (!fileExists) {
      dataFile.print("Timestamp,IntegrationTime_us,LED_State,Comment,Max_ADC");
      for (int i = 0; i < SPECTROGRAPH_CHANNELS; i++) {
        dataFile.print(",P");
        dataFile.print(i);
      }
      dataFile.println();
    }

    dataFile.print('"');
    dataFile.print(getFormattedTimestamp());
    dataFile.print('"');
    dataFile.print(',');
    dataFile.print(currentIntegrationTimeUs);
    dataFile.print(',');
    dataFile.print(ledState ? "ON" : "OFF");
    dataFile.print(',');
    dataFile.print('"');
    dataFile.print(userComment);
    dataFile.print('"');
    dataFile.print(',');
    dataFile.print(currentMaxIntensity);

    for (int i = 0; i < SPECTROGRAPH_CHANNELS; i++) {
      dataFile.print(',');
      dataFile.print(spectrographData[i]);
    }
    dataFile.println();
    dataFile.close();
  } else {
    Serial.println(F("[ERROR] Failed to open spectra_log.csv on SD card"));
  }
}

void writeBurstToSD() {
  bool fileExists = SD.exists("/spectra_log.csv");

  File dataFile = SD.open("/spectra_log.csv", FILE_APPEND);
  if (dataFile) {
    if (!fileExists) {
      dataFile.print("Timestamp,IntegrationTime_us,LED_State,Comment,Max_ADC");
      for (int i = 0; i < SPECTROGRAPH_CHANNELS; i++) {
        dataFile.print(",P");
        dataFile.print(i);
      }
      dataFile.println();
    }

    for (int b = 0; b < BURST_SIZE; b++) {
      dataFile.print('"');
      dataFile.print(getFormattedTimestamp());
      dataFile.print('"');
      dataFile.print(',');
      dataFile.print(burstIntegrationTimes[b]);
      dataFile.print(',');
      dataFile.print(ledState ? "ON" : "OFF");
      dataFile.print(',');
      dataFile.print('"');
      dataFile.print(userComment);
      dataFile.print('"');
      dataFile.print(',');
      dataFile.print(burstMaxIntensities[b]);

      for (int i = 0; i < SPECTROGRAPH_CHANNELS; i++) {
        dataFile.print(',');
        dataFile.print(burstBuffer[b][i]);
      }
      dataFile.println();
    }
    dataFile.close();
  } else {
    Serial.println(F("[ERROR] Failed to open /spectra_log.csv on SD card"));
  }
}

// ============================================================
// SERIAL COMMAND HANDLER
// ============================================================
void handleSerialCommands() {
  if (Serial.available() <= 0) {
    return;
  }

  String input = Serial.readStringUntil('\n');
  input.trim();
  String upperInput = input;
  upperInput.toUpperCase();

  if (upperInput.startsWith("INT ")) {
    autoIntegrationEnabled = false; 
    String valueString = input.substring(4);
    valueString.trim();
    unsigned long newInt = valueString.toInt();

    if (newInt > 0) {
      currentIntegrationTimeUs = constrain(newInt, minIntegrationTimeUs, maxIntegrationTimeUs);
      Serial.print(F("[CMD] Integration Time set to: "));
      Serial.print(currentIntegrationTimeUs);
      Serial.println(F(" us"));
    } else {
      Serial.println(F("[ERROR] Invalid integration time"));
    }
  }
  else if (upperInput.startsWith("LOG ")) {
    String valueString = input.substring(4);
    valueString.trim();
    unsigned long seconds = valueString.toInt();

    if (seconds > 0) {
      logIntervalMs = seconds * 1000UL;
      timedLoggingActive = true;
      lastLogTime = millis();
      Serial.print(F("[CMD] Timed logging enabled every "));
      Serial.print(seconds);
      Serial.println(F(" seconds."));
    } else {
      timedLoggingActive = false;
      Serial.println(F("[CMD] Timed logging disabled."));
    }
  }
  else if (upperInput.equalsIgnoreCase("A")) {
    autoIntegrationEnabled = !autoIntegrationEnabled;
    Serial.print(F("[CMD] Auto-Integration -> "));
    Serial.println(autoIntegrationEnabled ? F("ENABLED (Target Max: 2500)") : F("DISABLED"));
  }
  else if (upperInput.equalsIgnoreCase("L")) {
    ledState = !ledState;
    Serial.print(F("[CMD] LED Strobe -> "));
    Serial.println(ledState ? F("ENABLED") : F("DISABLED"));
  }
  else if (upperInput.equalsIgnoreCase("S")) {
    requestSaveToSD = true;
    Serial.println(F("[CMD] Single save requested for next frame..."));
  }
  else if (upperInput.equalsIgnoreCase("B")) {
    isBursting = true;
    burstCount = 0;
    Serial.println(F("[CMD] Starting 10-frame burst capture..."));
  }
  else if (upperInput.startsWith("COMMENT ")) {
    userComment = input.substring(8);
    Serial.print(F("[CMD] Comment updated: "));
    Serial.println(userComment);
  }
  else if (upperInput.equals("HELP")) {
    printHelpMenu();
  }
  else {
    Serial.print(F("[ERROR] Unknown command: "));
    Serial.println(input);
  }
}

// ============================================================
// HELP MENU
// ============================================================
void printHelpMenu() {
  Serial.println(F("----------------------------------------"));
  Serial.println(F(" C12880MA COMMAND MENU"));
  Serial.println(F("----------------------------------------"));
  Serial.println(F("INT <us>        - Set integration time & disable auto-int"));
  Serial.println(F("LOG <sec>       - Log spectrum every N seconds (LOG 0 to stop)"));
  Serial.println(F("A               - Toggle Auto-Integration ON/OFF (Target: 2500)"));
  Serial.println(F("L               - Toggle LED illumination strobe ON/OFF"));
  Serial.println(F("S               - Save single spectrum frame to SD card"));
  Serial.println(F("B               - Burst capture 10 frames to RAM and save to CSV"));
  Serial.println(F("COMMENT <text>  - Set log comment string (e.g. COMMENT SampleA)"));
  Serial.println(F("HELP            - Show this menu"));
  Serial.println(F("----------------------------------------"));
  Serial.println();
}

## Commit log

2026-09-14 Revise README for clarity and additional details
    Updated descriptions for clarity and added details on sensor layout and hardware components.
2026-09-16 Fix formatting in Hardware Bill of Materials
    Corrected formatting in the Hardware Bill of Materials section.
2026-09-16 Fix formatting in Hardware Bill of Materials section
    Updated the wavelength range formatting for clarity.
2026-09-24 Enhance README with correlation analysis details
    Added detailed explanations for correlation analysis and physical coupling.
